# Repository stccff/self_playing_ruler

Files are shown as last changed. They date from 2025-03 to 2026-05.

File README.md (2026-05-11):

# Cyberuler: A Self-Playing Ruler

[English](README.md) | [中文](README_zh.md)


[]()

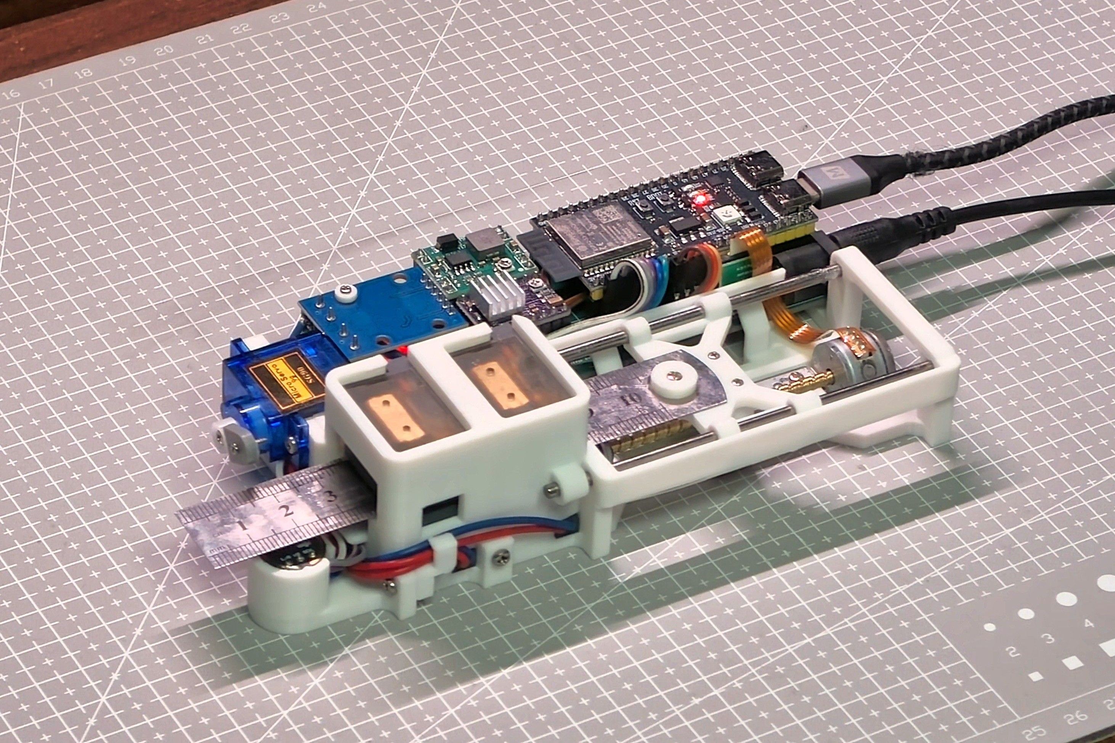
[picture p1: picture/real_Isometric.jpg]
Cyberuler


> An automated musical instrument that turns an ordinary steel ruler into a playable synthesizer — controlled by stepper motors, servos, electromagnets, and MIDI.

## Contents

- ✨ [Features](#features)
- 🎵 [A Note on Timbre](#a-note-on-timbre)
- 📂 [Repository Structure](#repository-structure)
- 🛠️ [Hardware at a Glance](#hardware-at-a-glance)
- ⚙️ [PCB Configuration Options](#pcb-configuration-options)
- 🚀 [Getting Started](#getting-started)
  - [Build Prerequisites](#build-prerequisites)
  - [Serial Terminal Commands](#serial-terminal-commands)
- 🗺️ [Roadmap](#roadmap-the-stationery-band)
- 👤 [Author](#author)
- 📄 [License](#license)

## 🎥 Demo



## ✨ Features

- **Pitch Control:** A stepper motor with a lead screw slides the ruler to change the effective vibrating length, producing different pitches.
- **Plucking Mechanism:** A high-speed servo strums the ruler. Four electromagnets (H-bridge driven, two top and two bottom) clamp and release the ruler for clean note articulation.
- **Acoustic Calibration:** An INMP441 I2S microphone captures the ruler's real acoustic response. Fast Fourier Transform (FFT) analysis builds a frequency-to-position mapping — no manual tuning required.
- **NLS Curve Fitting:** Uses Levenberg-Marquardt nonlinear least squares to fit measured frequency data to a `f = k/(pos + a)² + b` model for accurate pitch interpolation across the full range.
- **USB MIDI Input:** Connects as a USB MIDI device via TinyUSB. Responds to Note On/Off messages with velocity sensitivity — play it live from any MIDI keyboard or DAW.
- **USB Microphone:** The I2S microphone is also exposed as a USB Audio (UAC 2.0) input — the ruler doubles as a USB mic for your computer.
- **Serial Terminal REPL:** Built-in command-line interface with line editing, ANSI arrow-key navigation, and command history. Full control over motors, calibration, and diagnostics.

## 🎵 A Note on Timbre

A vibrating string (guitar, piano) follows the wave equation — its overtones are integer multiples of the fundamental, producing a familiar harmonic sound. A steel ruler, however, is a cantilever beam governed by the Euler-Bernoulli beam equation. Under one-end-fixed, one-end-free boundary conditions, its natural frequencies are:

$$\omega_n = \beta_n^2 \sqrt{\frac{EI}{\rho A L^4}}$$

where $\beta_n$ are roots of $1 + \cos\beta \cosh\beta = 0$. The first overtone is roughly **6.26×** the fundamental, and the second is **17.55×** — neither is an integer multiple.

This means the ruler's overtones are inherently inharmonic. Calibration ensures the fundamental frequency is pitch-accurate, but the overtone structure is a physical given — the instrument will always carry a raw, slightly "imperfect" timbre. That is not a flaw; it is the character of the instrument.

## 📂 Repository Structure

| Directory | Description |
|---|---|
| `v1/code/` | ESP-IDF firmware (C) — motor control, FFT, USB MIDI, REPL terminal |
| `v1/model_A_1.2/` | SolidWorks 3D models + printable STL files |
| `v1/model_legacy/` | Archived older model versions (A_1.0, A_1.1, B) |
| `v1/pcb/` | PCB design files (STEP, Gerber), [OSHWHub project](https://oshwhub.com/stccff/self_play_ruler) |
| `v1/bom_zh.xlsx` | Bill of materials |
| `prototype/` | Early prototype — firmware, Python host scripts, 3D models |
| `tools/` | Auxiliary tools and drivers |
| `picture/` | Project photos, renders, and diagrams |

## 🛠️ Hardware at a Glance

- **MCU:** ESP32-S3 DevKitC
- **PCB:** Custom mainboard (fabricated by JLCPCB) — integrates power, motor drivers, microphone, USB MIDI, and USB Audio. Gerber files in `v1/pcb/`, [OSHWHub project page](https://oshwhub.com/stccff/self_play_ruler)
- **Stepper Driver:** DRV8825 module (A4988 optional)
- **Electromagnet Driver:** L9110S module
- **Voltage Regulator:** MP1845EN module (Mini360 optional)
- **Stepper Motor:** Lead-screw stepper salvaged from a CD-ROM drive
- **Servo:** SG90 (strumming)
- **Electromagnets:** x4 — 2 top, 2 bottom
- **Audio:** INMP441 I2S microphone
- **Power:** 12V DC barrel jack (external power supply required)
- **Chassis:** 3D-printed parts + 150mm steel ruler

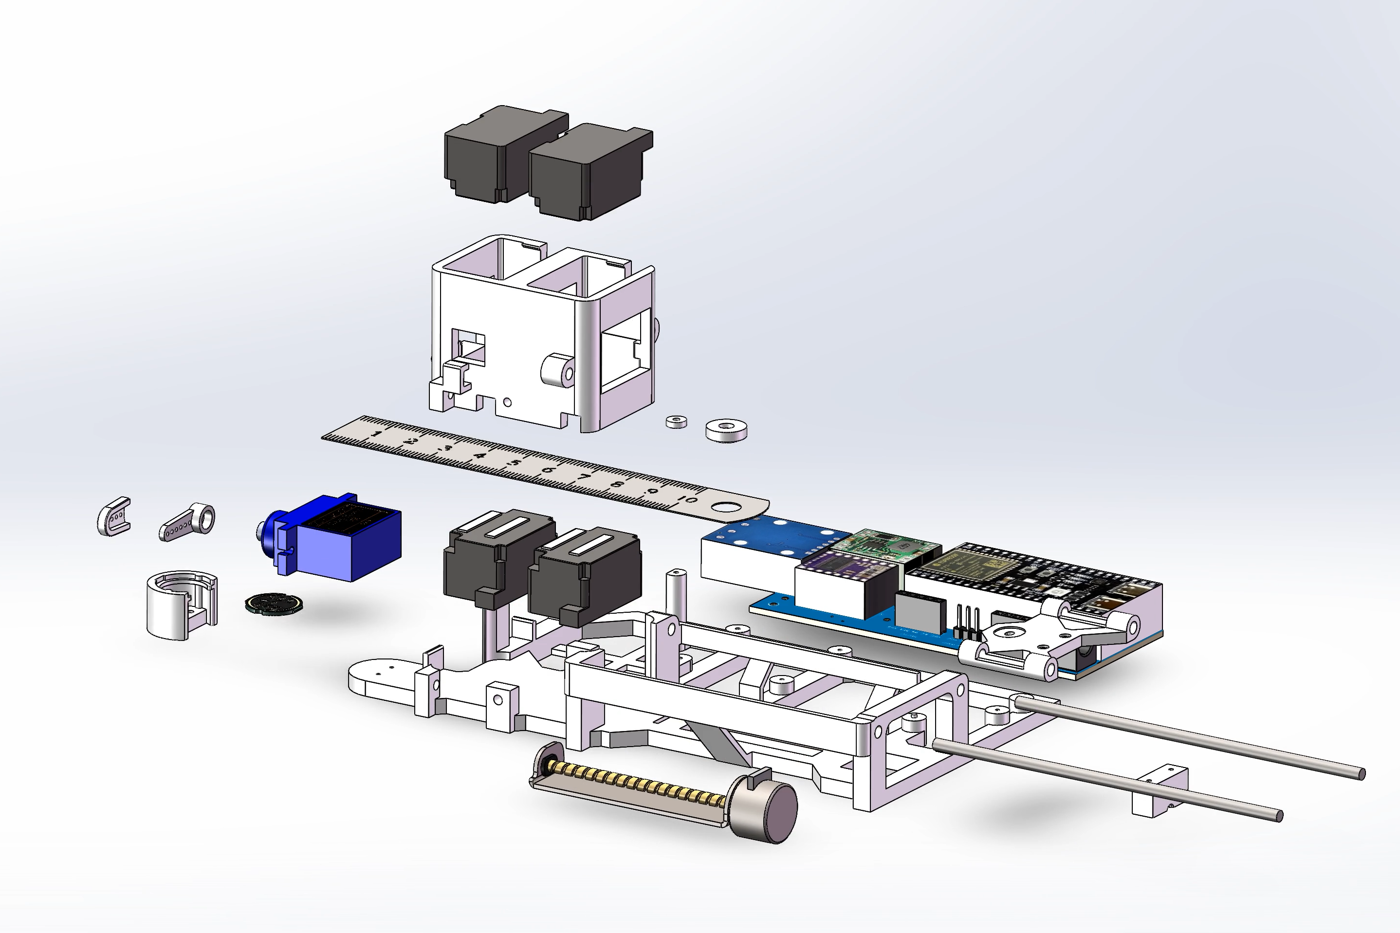
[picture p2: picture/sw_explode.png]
Exploded view


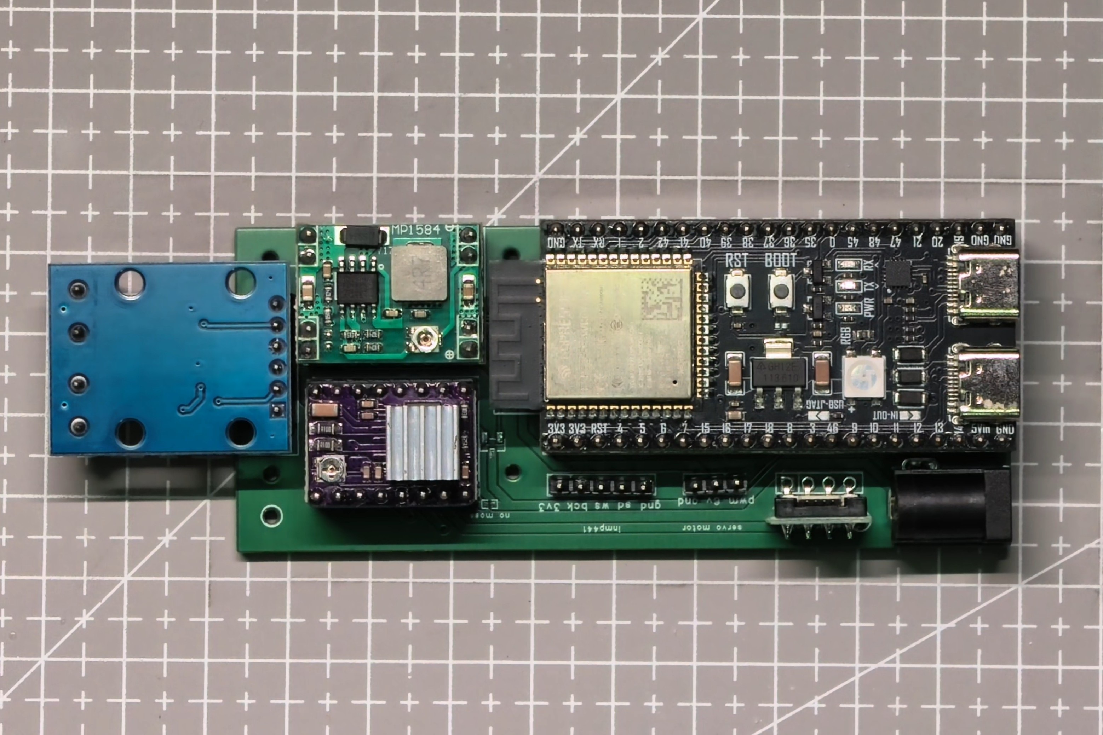
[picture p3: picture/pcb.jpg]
Custom PCB


See `v1/bom_zh.xlsx` for the detailed bill of materials.

> ⚠️ **Important Notes:**
> - The ESP32-S3 DevKitC is powered via USB. The 12V DC input supplies the motors and drivers only — the device will not function without USB connected.
> - If the **SGM2521YS8** power-switch IC is not populated on the PCB, do **not** disconnect USB while 12V power remains connected. Doing so cuts power to the ESP32, leaving the DRV8825 control pins floating and the stepper motor in an abnormal state that causes overheating.
> - Set the **SG90 servo supply voltage to 6V**. The firmware's strum timing was calibrated at 6V; a different voltage will throw off the timing.
> - Set the **DRV8825 current limit** appropriately. Too low and the stepper motor will stall; too high and it will overheat.

## ⚙️ PCB Configuration Options

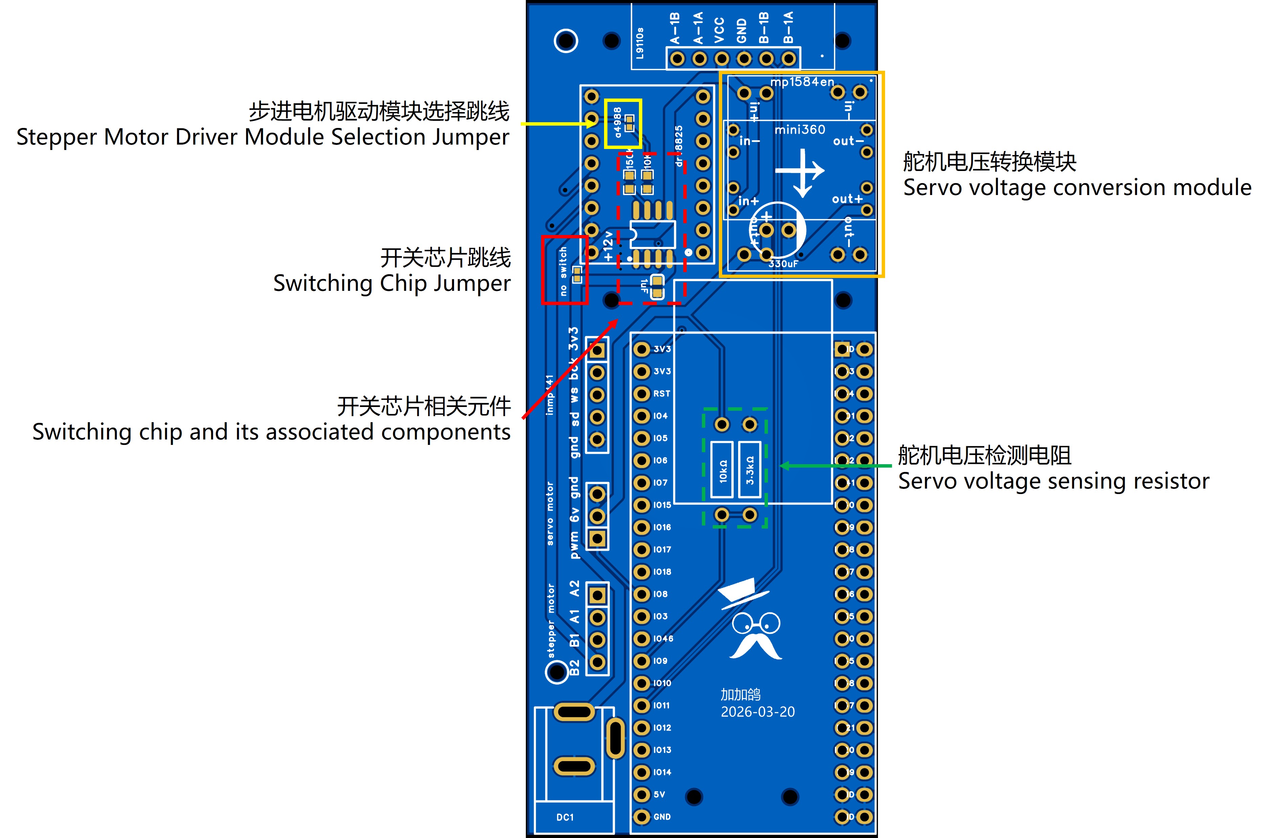
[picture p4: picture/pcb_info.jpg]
PCB jumpers and options


- **Stepper driver:** DRV8825 (default) or A4988 — solder the jumper pads when using A4988.
- **Servo voltage regulator:** MP1845EN (default) or Mini360.
- **Power-switch IC (SGM2521YS8):** Optional — prevents the stepper driver from entering an abnormal state when the MCU loses power (see Important Notes above).
- **Servo voltage sense resistor:** Optional — enables ADC-based voltage monitoring from the dev board, useful for tuning servo voltage without a multimeter.

## 🚀 Getting Started

1. **Print the parts:** STL files are in `v1/model_A_1.2/output/`.
2. **Assemble the hardware:** Mount motors, ruler, electromagnets, and PCB onto the printed chassis.
3. **Flash the firmware:** Build and upload the ESP-IDF project in `v1/code/` to your ESP32-S3.
4. **Calibrate:** Press the BOOT button on the dev board (single-click triggers auto-calibration), or run the `ftinit` command via the serial terminal. The microphone listens as the ruler is plucked across its range to build the pitch map.

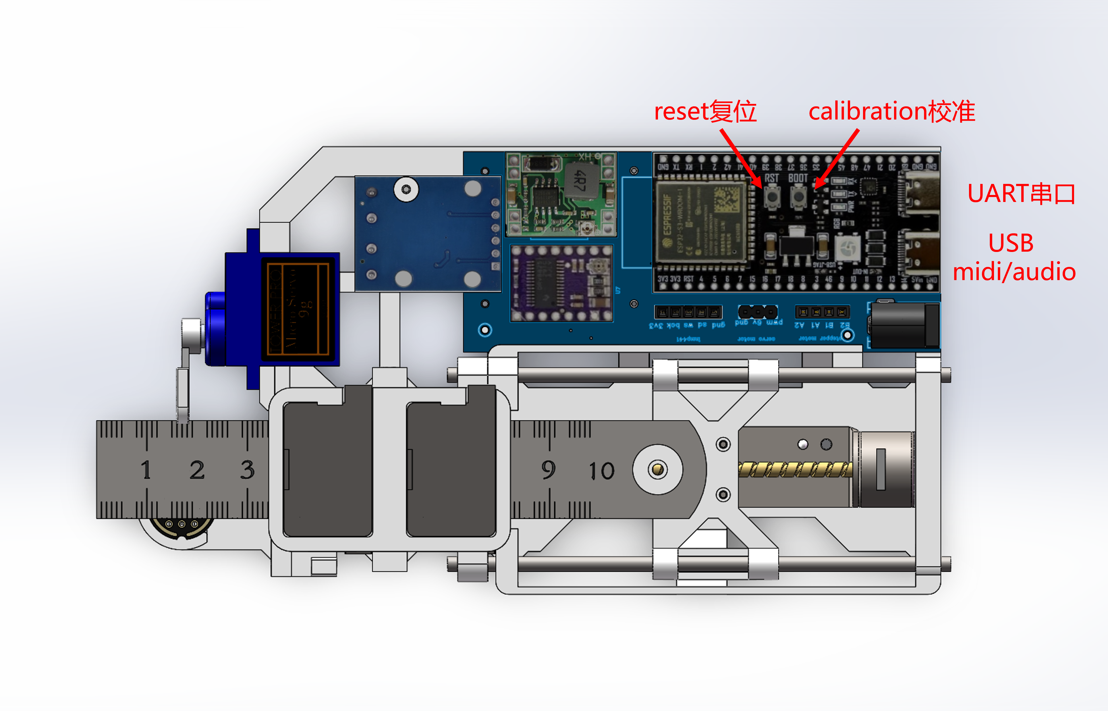
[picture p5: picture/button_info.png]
BOOT button for calibration

5. **Play:** Connect a USB MIDI keyboard, or use the serial terminal (`p` command) to play notes directly.

### Build Prerequisites

- **ESP-IDF** v5.0 or later (target: ESP32-S3)
- Dependencies (auto-resolved by IDF Component Manager):
  - `espressif/esp-dsp` — FFT library
  - `espressif/tinyusb` — USB MIDI device stack
  - `espressif/button` — GPIO button driver
  - `espressif/led_strip` — WS2812 RGB LED driver

```bash
cd v1/code
idf.py set-target esp32s3
idf.py build
idf.py -p <PORT> flash
```

### Serial Terminal Commands

Connect via UART (115200 baud) to access the REPL. Key commands:

| Command | Description |
|---|---|
| `help` | List all available commands |
| `ftinit` | Rebuild frequency calibration table |
| `p <note>` | Play a note by numbered musical notation (e.g. `p 1.`) |
| `midivelocity <0\|1>` | Toggle MIDI velocity sensitivity |
| `compiletime` | Print firmware build timestamp |

## 🗺️ Roadmap: The Stationery Band

The Self-Playing Ruler is the first instrument in a larger vision — a full desk-sized automated orchestra built from everyday stationery.

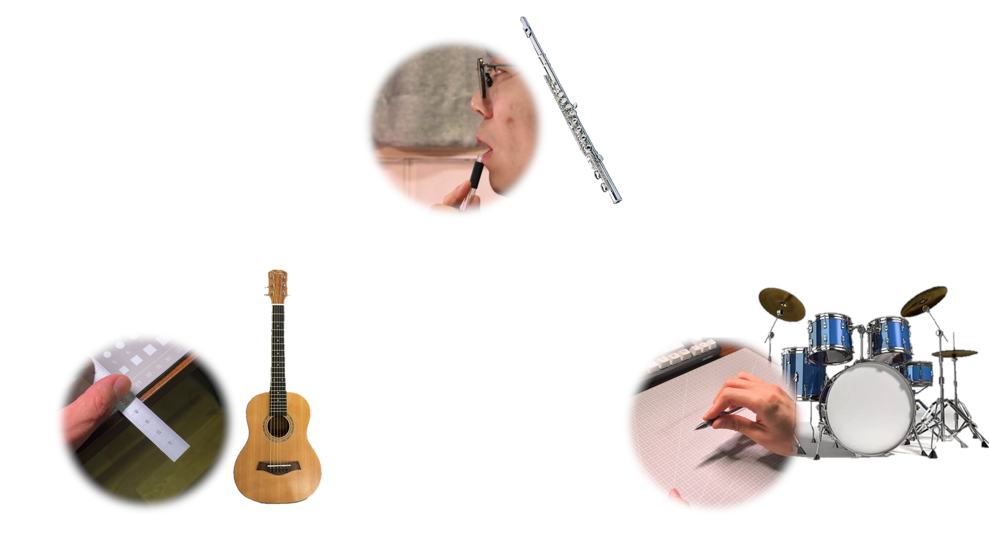
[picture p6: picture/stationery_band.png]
Stationery Band


- [x] **The Guitar/Bass:** Cyberuler (This project)
- [ ] **The Flute:** Automated Wind Pen
- [ ] **The Drums:** Percussive Pen and Desk Tappers
- [ ] **The Conductor:** Central sync hub for all instruments

## 👤 Author

**stccff** — [github.com/stccff](https://github.com/stccff) — [913602792@qq.com](mailto:913602792@qq.com)

Feedback, questions, and build stories are always welcome. If you make your own, I'd love to see it.

## 📄 License

This project is licensed under [CC BY-NC-SA 4.0](https://creativecommons.org/licenses/by-nc-sa/4.0/) — you are free to share and adapt for non-commercial purposes, with attribution and under the same license.

See the [LICENSE](LICENSE) file for details.

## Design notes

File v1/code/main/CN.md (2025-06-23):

# 使用说明

1.傅里叶变换，如果内存不够用，可以使用psram，需要在menuconfig中配置mode(quad/oct)
2.需要配置硬件版本

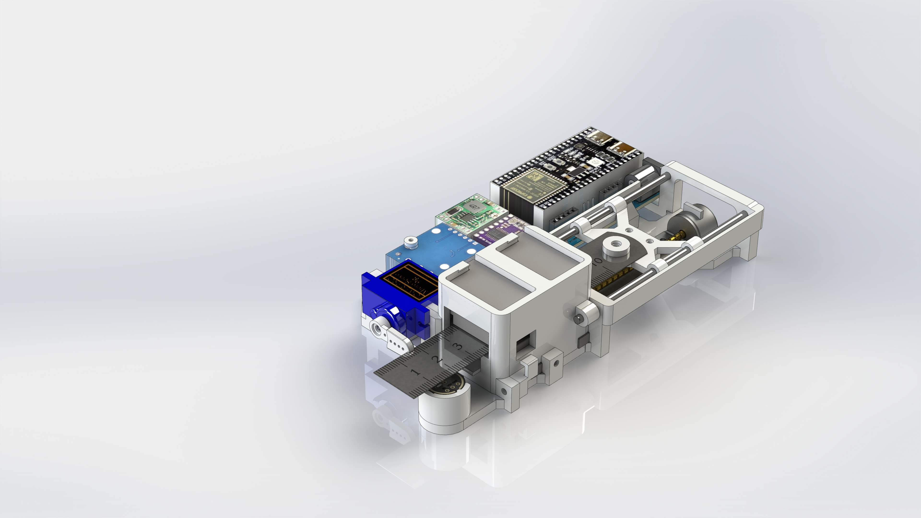
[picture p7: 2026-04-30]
picture/render_photo360.JPG

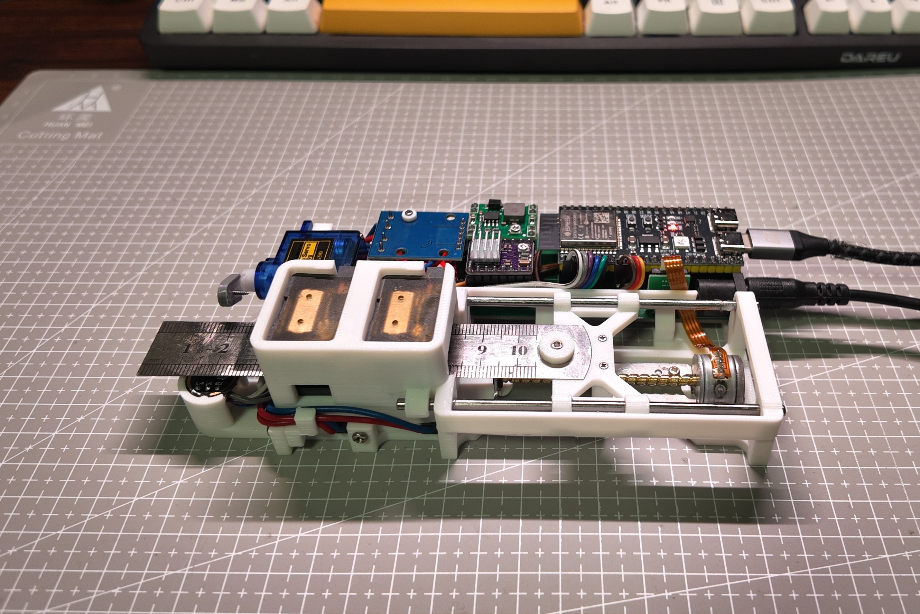
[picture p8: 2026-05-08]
picture/real_front.jpg

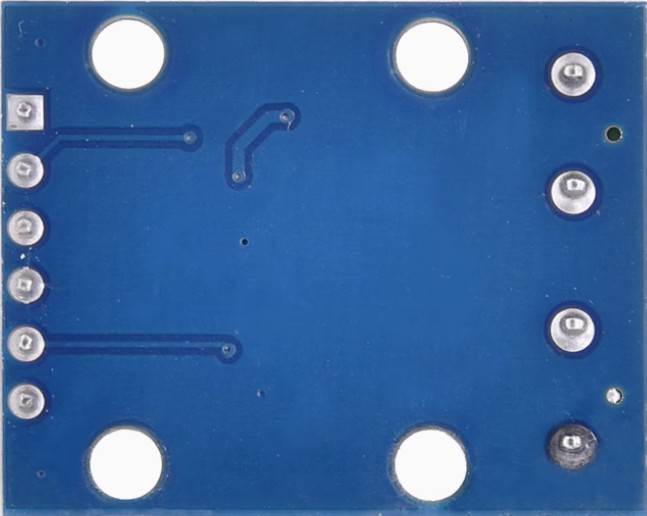
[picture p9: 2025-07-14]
v1/model_A_1.2/texture/l9110s.jpg

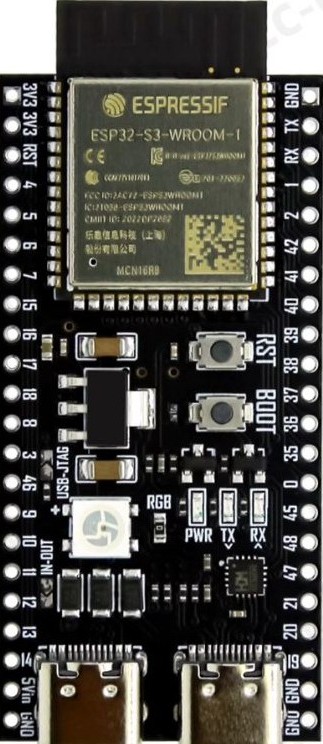
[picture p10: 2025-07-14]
v1/model_A_1.2/texture/esp32s3-devkitc.jpg

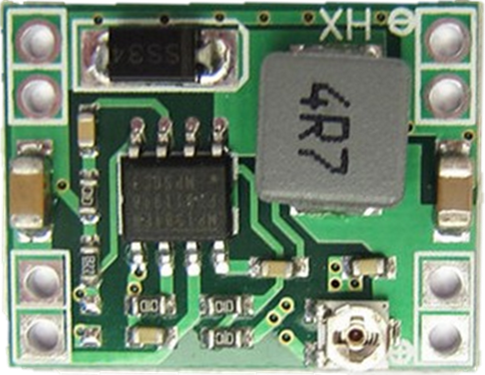
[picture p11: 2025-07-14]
v1/model_A_1.2/texture/mp1584en.png

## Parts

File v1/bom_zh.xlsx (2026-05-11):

是否可选 | 类别 | 名称 | 连接对象 | 数量 | 参考单价 | 共计 | 参考购买链接 | 开源链接
必要 | 器件 | esp32s3-devkitc开发板 |  | 1 | 27.9 | 27.9 | https://item.taobao.com/item.htm?abbucket=20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
必要 | 器件 | drv8825/a4988步进电机驱动模块 |  | 1 | 4.7 | 4.7 | https://detail.tmall.com/item.htm?id=609793364367&skuId=4291793301378
必要 | 器件 | MP1584EN/mini360 可调降压模块 |  | 1 | 1.57 | 1.57 | https://item.taobao.com/item.htm?abbucket=20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
必要 | 器件 | sg90舵机 |  | 1 | 4.2 | 4.2 | https://detail.tmall.com/item.htm?id=678498890304&skuId=5719859296396
必要 | 器件 | Y15-56丝杆步进电机（光驱拆机） |  | 1 | 4.9 | 4.9 | https://item.taobao.com/item.htm?id=642594293054
必要 | 器件 | 双L9110s H桥模块 |  | 1 | 2.3 | 2.3 | https://item.taobao.com/item.htm?id=654074095766&skuId=4712438424221
必要 | 器件 | inmp441数字麦克风模块 |  | 1 | 3.8 | 3.8 | https://item.taobao.com/item.htm?id=608292096518
必要 | 器件 | DC12V-24V电磁铁（拆机） |  | 4 | 1.9 | 7.6 | https://item.taobao.com/item.htm?id=578507772290
必要 | 器件 | DC-12V2A直流电源？？？？ |  | 1 | 16 | 16 | https://item.taobao.com/item.htm?detail_redpacket_pop=true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
必要 | 器件 | usb type-c数据线 |  | 2 | 1.9 | 3.8 | https://item.taobao.com/item.htm?abbucket=20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
必要 | 器件 | 4P FPC 1.0mm -> 2.54转换板 |  | 1 | 1.4 | 1.4 | https://item.taobao.com/item.htm?from=cart&id=552721736398&skuId=4760839875224
必要 | 结构 | 结构模型 |  | 1 | 10 | 10 | 3D打印
必要 | 结构 | 10cm超薄钢尺 |  | 1 | 0.4 | 0.4 | https://item.taobao.com/item.htm?id=592441007488&skuId=4073794208655
必要 | 结构 | 3mm*10cm光轴 |  | 2 | 0.68 | 1.36 | https://detail.tmall.com/item.htm?id=680516964370&skuId=5675436564491
必要 | 结构 | 润滑脂 |  | 1 | 1 | 1
必要 | 结构 | M2*5？圆头螺丝 |  | 3 | 0.05 | 0.15 | https://item.taobao.com/item.htm?id=755201657209&skuId=5379709963747
必要 | 结构 | M2*5螺帽 |  | 3 | 0.05 | 0.15 | https://item.taobao.com/item.htm?id=755201657209&skuId=5379709963747
必要 | 结构 | M2.5*10自攻螺丝 |  | 5 | 0.05 | 0.25 | https://item.taobao.com/item.htm?id=755201657209&skuId=5379709963747
必要 | 结构 | M1.4*7自攻螺丝 |  | 10 | 0.05 | 0.5 | https://detail.tmall.com/item.htm?id=682216315966
必要 | PCB | 主板PCB |  | 1 | 0 | 0 | 嘉立创PCB免费打样
必要 | 元件 | 1x22P排母 | esp32s3 | 2 | 0.22 | 0.44 | https://item.taobao.com/item.htm?id=15813904618
必要 | 元件 | 1x8P排母 | drv8825 | 2 | 0.12 | 0.24 | https://item.taobao.com/item.htm?id=15813904618
必要 | 元件 | 1x2P排母 | MP1584EN | 4 | 0.07 | 0.28 | https://item.taobao.com/item.htm?id=15813904618
必要 | 元件 | 1x6P排母 | L9110s | 1 | 0.1 | 0.1 | https://item.taobao.com/item.htm?id=15813904618
必要 | 元件 | 1x40P排针（掰开使用） | 多个 | 1 | 0.1 | 0.1 | https://item.taobao.com/item.htm?id=14591564405
必要 | 元件 | 杜邦线（约21cm） | mic | 6 | 0.1 | 0.6 | https://detail.tmall.com/item.htm?id=14466195609&skuId=5922240227983
必要 | 元件 | DC电源插座，5.5-2.1mm |  | 1 | 0.06 | 0.06 | https://item.taobao.com/item.htm?id=14986857930
必要 | 元件 | 电解电容330uF |  | 1 | 0.15 | 0.15
可选 | 元件 | 直插电阻10k |  | 1 | 0.02 | 0.02
可选 | 元件 | 直插电阻3.3k |  | 1 | 0.02 | 0.02
可选 | 元件 | 负载开关SGM2521YS8G/TR |  | 1 | 5 | 5
可选 | 元件 | 贴片电容1uF |  | 1 | 0.05 | 0.05
可选 | 元件 | 贴片电阻10K |  | 1 | 0.05 | 0.05
可选 | 元件 | 贴片电阻150K |  | 1 | 0.05 | 0.05
 |  |  |  |  | 总计 | 93.95

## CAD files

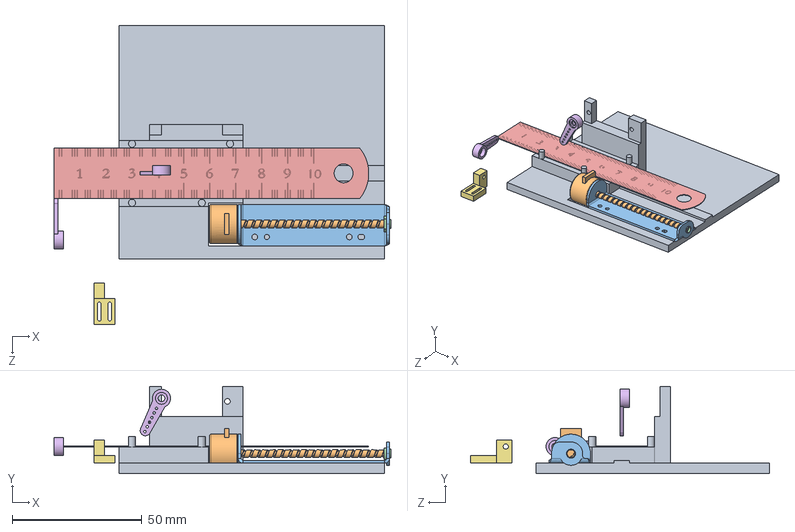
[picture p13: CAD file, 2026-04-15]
prototype/model/尺子演奏器验证机.SLDASM
129.8 x 33.6 x 115.2 mm
步进电机
丝杆底座
丝杆衬套
10cm薄尺
servo_horn(sg90) x 2
底板
舵机固定架L镜向

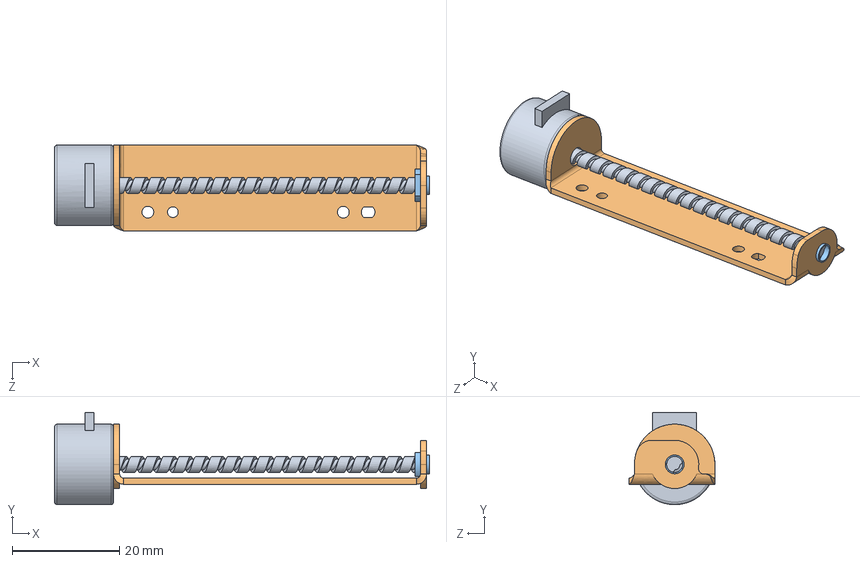
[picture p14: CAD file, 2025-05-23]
prototype/model/光驱丝杆步进电机.SLDASM
69.8 x 17.2 x 16.0 mm
步进电机
丝杆底座
丝杆衬套

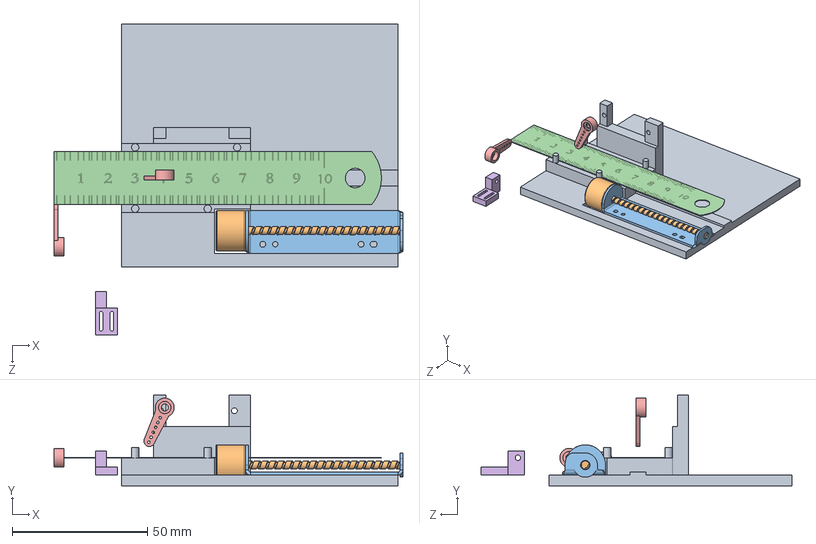
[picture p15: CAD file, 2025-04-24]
prototype/model/动画.SLDASM
129.2 x 33.6 x 115.0 mm
步进电机
丝杆底座
10cm薄尺
servo_horn(sg90) x 2
底板
舵机固定架L镜向

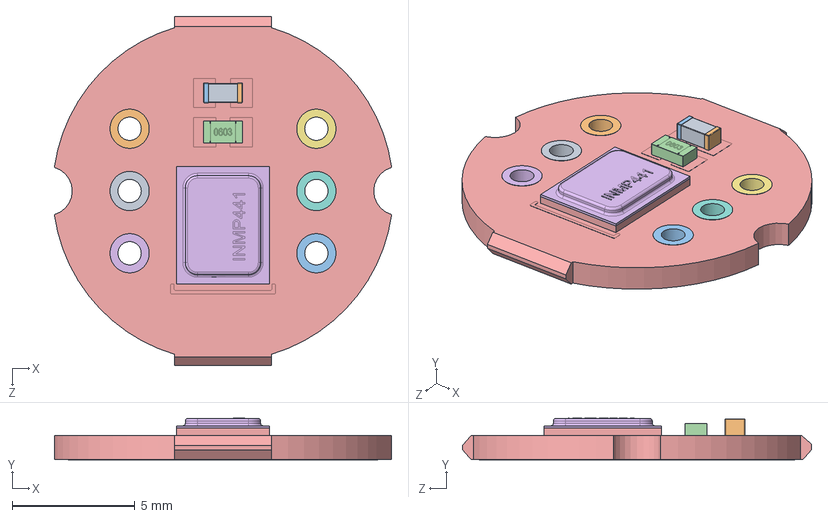
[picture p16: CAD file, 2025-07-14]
v1/model_A_1.2/INMP441.SLDASM
13.8 x 1.70 x 14.2 mm
Part 3.step
Part 2.step
Part 1.step
0603 Resistor.step
INMP441 I2S Microphone Module.step
INMP441 I2S Microphone Module-0.step
INMP441 I2S Microphone Module-1.step
INMP441 I2S Microphone Module-2.step
INMP441 I2S Microphone Module-3.step
INMP441 I2S Microphone Module-4.step
INMP441 I2S Microphone Module-5.step
INMP441 I2S Microphone Module-6.step
INMP441 I2S Microphone Module-7.step
INMP441 I2S Microphone Module-8.step

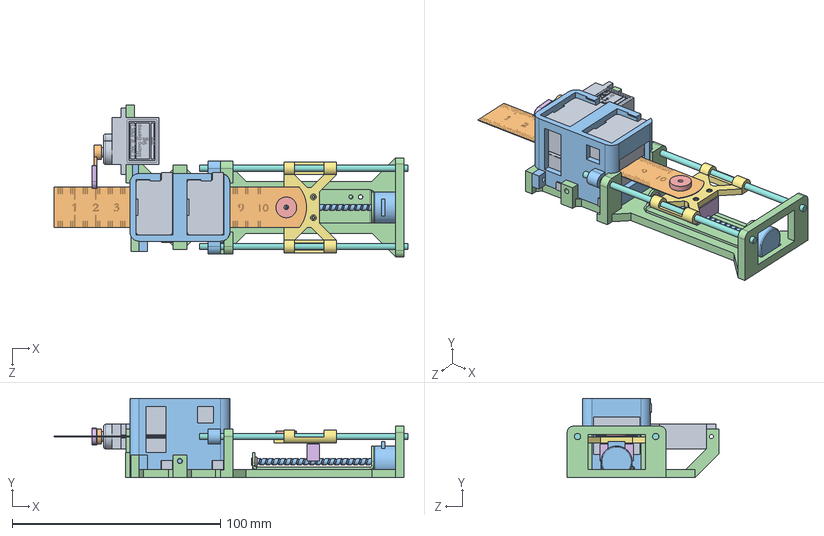
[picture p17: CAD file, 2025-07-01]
v1/model_A_1.2/钢尺琴A_1.2.SLDASM
169.9 x 38.1 x 72.8 mm
电磁铁 x 4
10cm薄尺
步进电机
丝杆底座
丝杆衬套
丝杆连接器
滑块（新）
光轴3x100 x 2
servo_motor(SG90)
servo_horn(sg90)
电磁铁固定座
底座（新）
固定块
拨片

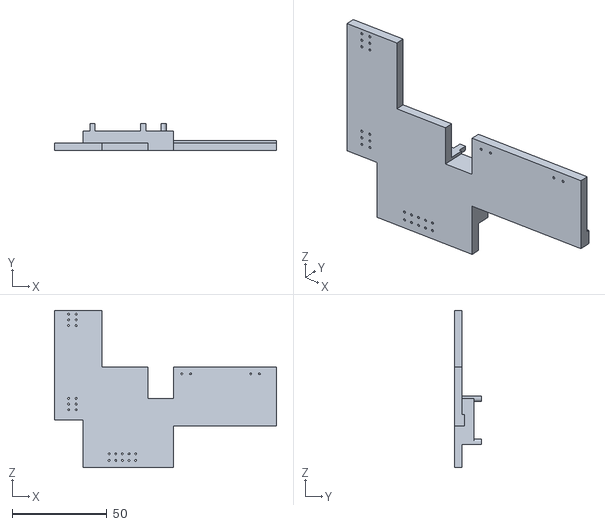
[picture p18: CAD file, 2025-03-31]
prototype/model/stl/尺子演奏器验证机 - 底板-1.STL
117.3 x 14.3 x 83.0

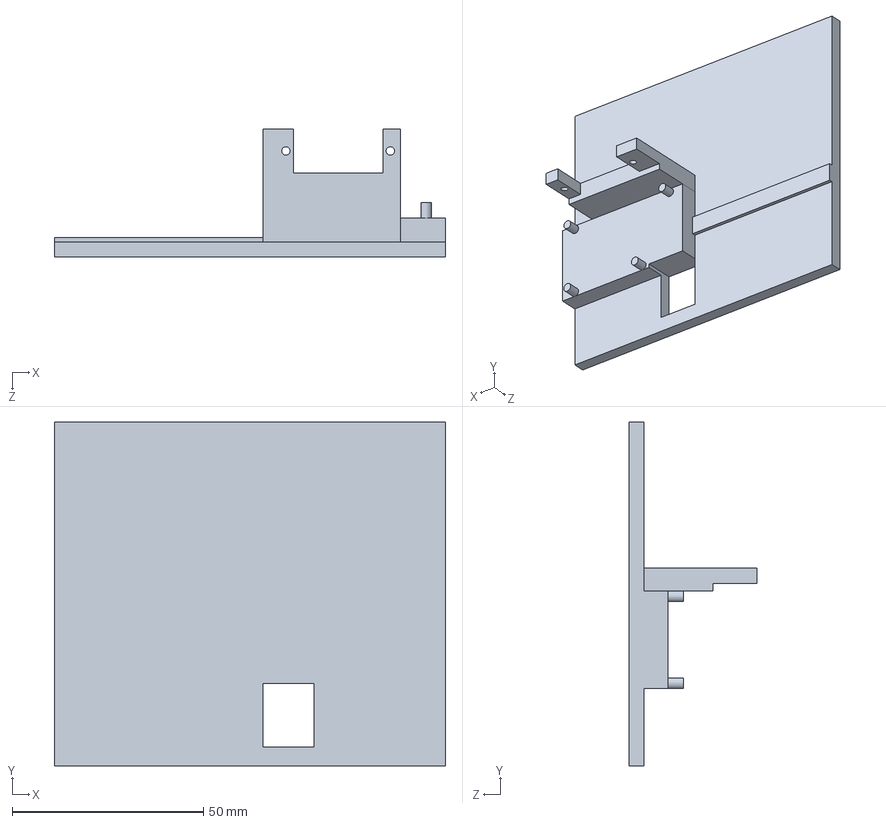
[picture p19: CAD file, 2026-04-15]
prototype/model/底板.SLDPRT
102.3 x 89.9 x 33.6 mm

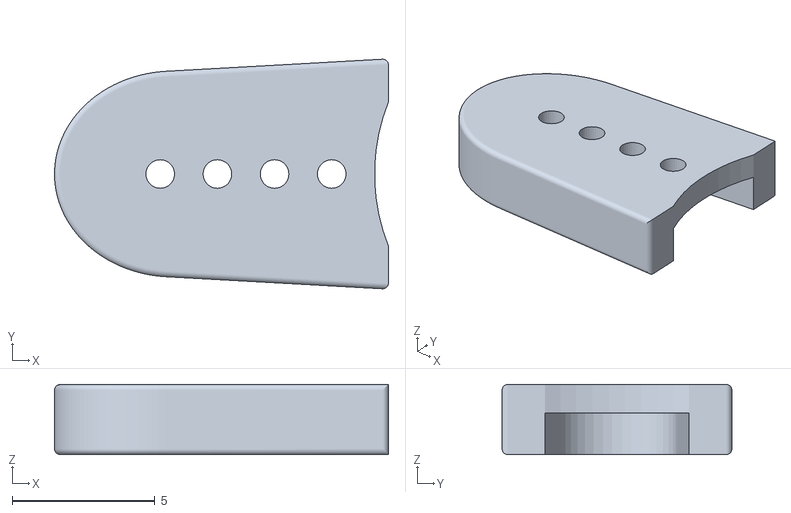
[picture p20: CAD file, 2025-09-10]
v1/model_A_1.2/output/钢尺琴A_1.2 - 拨片+-1.STL
11.7 x 8.03 x 2.45

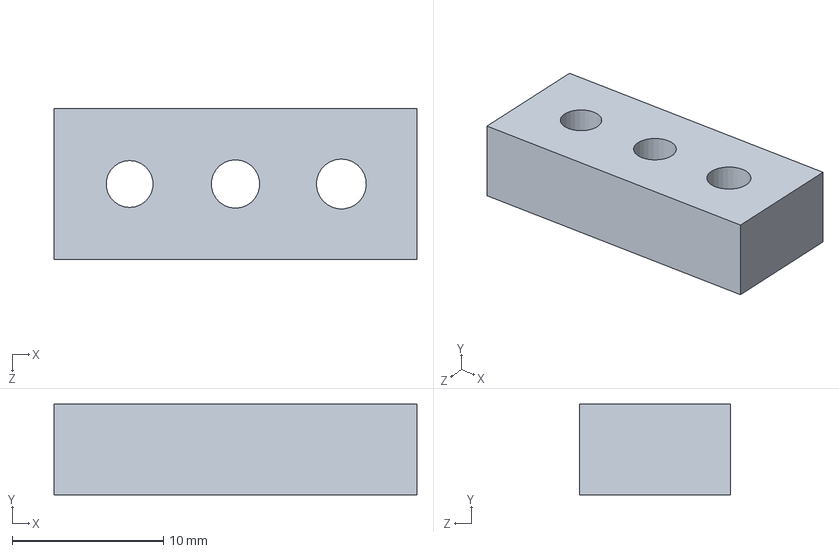
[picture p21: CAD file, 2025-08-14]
v1/model_A_1.2/test/钢轴孔径测试.SLDPRT
24.0 x 6.00 x 10.0 mm

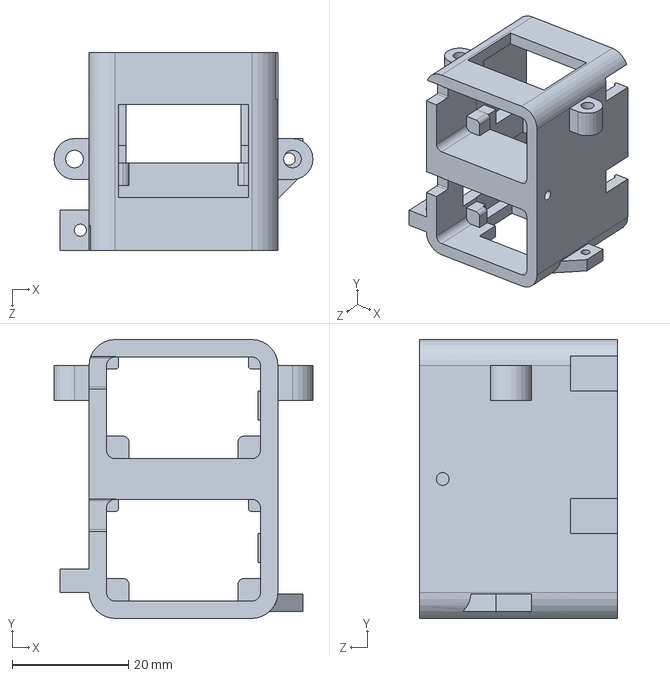
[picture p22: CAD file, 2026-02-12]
v1/model_A_1.2/电磁铁固定座.SLDPRT
44.6 x 48.0 x 34.1 mm

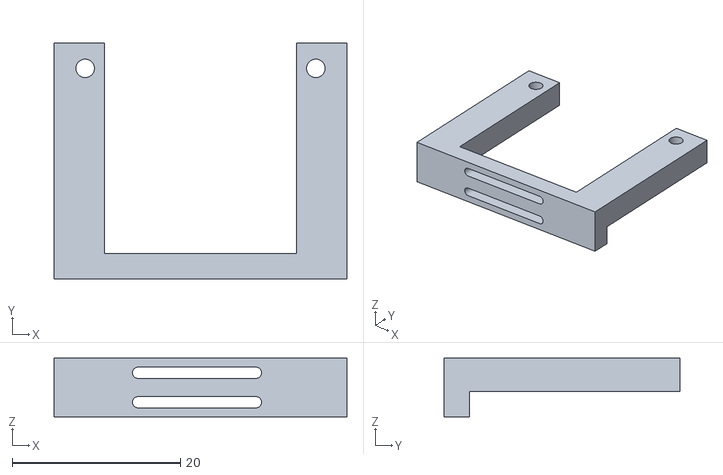
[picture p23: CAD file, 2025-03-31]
prototype/model/stl/尺子演奏器验证机 - 舵机固定器(按压)-1.STL
34.8 x 28.0 x 7.00

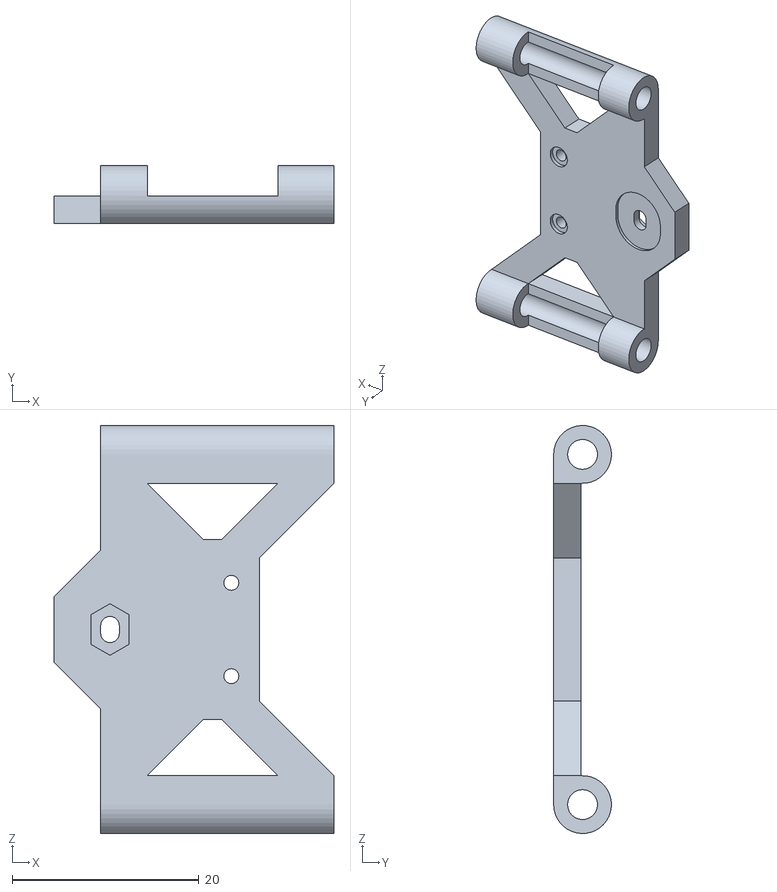
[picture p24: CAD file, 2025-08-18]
v1/model_A_1.2/output/钢尺琴A_1.2 - 滑块（新）-1.STL
30.0 x 6.19 x 43.7

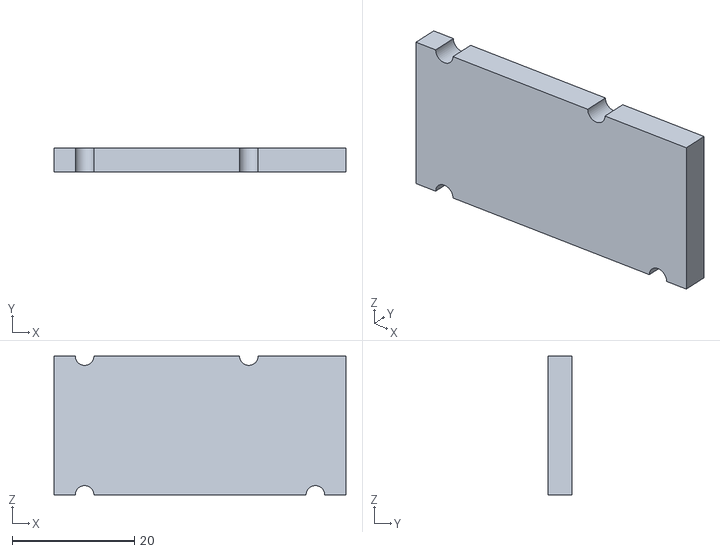
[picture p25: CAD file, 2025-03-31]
prototype/model/stl/尺子演奏器验证机 - 盖板-1.STL
47.7 x 4.00 x 22.7

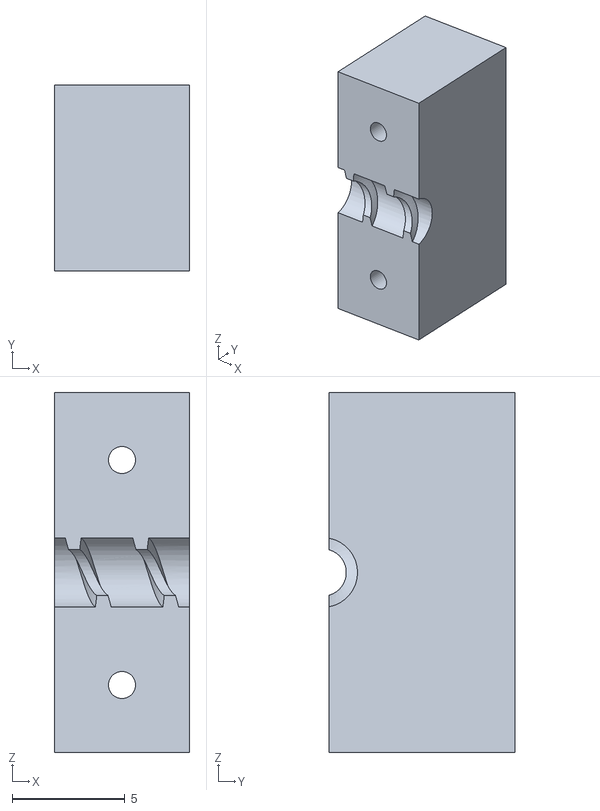
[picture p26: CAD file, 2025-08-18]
v1/model_A_1.2/output/钢尺琴A_1.2 - 丝杆连接器_优化版-1.STL
6.00 x 8.28 x 16.0

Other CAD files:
v1/model_A_1.2/光驱丝杆步进电机.SLDASM
prototype/model/舵机固定架L镜向.SLDPRT
v1/model_A_1.2/mic固定座.SLDPRT
prototype/model/舵机固定架L.SLDPRT
prototype/model/stl/尺子演奏器验证机 - 10cm薄尺-1.STL
prototype/model/stl/尺子演奏器验证机 - servo_horn(sg90)-1.STL
prototype/model/stl/尺子演奏器验证机 - servo_horn(sg90)-2.STL
prototype/model/stl/尺子演奏器验证机 - servo_motor(SG90)-1.STL
prototype/model/stl/尺子演奏器验证机 - servo_motor(SG90)-2.STL
prototype/model/stl/尺子演奏器验证机 - 光驱丝杆步进电机-1 丝杆底座-1.STL
prototype/model/stl/尺子演奏器验证机 - 光驱丝杆步进电机-1 步进电机-2.STL
prototype/model/stl/尺子演奏器验证机 - 固定帽-1.STL
prototype/model/stl/尺子演奏器验证机 - 滑块-1.STL
prototype/model/stl/尺子演奏器验证机 - 舵机固定架L-1.STL
prototype/model/stl/尺子演奏器验证机 - 舵机固定架L镜向-3.STL
prototype/model/丝杆衬套.SLDPRT
prototype/model/固定帽.SLDPRT
prototype/model/滑块.SLDPRT
prototype/model/盖板.SLDPRT
prototype/model/舵机固定器(按压).SLDPRT
v1/model_A_1.2/10cm薄尺.SLDPRT
v1/model_A_1.2/output/钢尺琴A_1.2 - mic固定座-1.STL
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

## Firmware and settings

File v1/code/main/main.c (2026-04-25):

#include <stdio.h>
#include <stdlib.h>
#include <string.h>
#include "freertos/FreeRTOS.h"
#include "freertos/task.h"
#include "freertos/event_groups.h"
#include "esp_system.h"
#include "esp_log.h"
#include "servo_motor.h"
#include "step_motor.h"
#include "ruler.h"
#include "uart_ctrl.h"
#include "terminal.h"
#include "digital_mic.h"
#include "h_bridge.h"
#include "tinyusb_device.h"
#include "play.h"
#include "nvs_flash.h"
#include "key.h"
#include "rgb_led.h"

#define TAG "MAIN"

/*
 vTaskGetRunTimeStats() 使用
 注意:
 使用 vTaskGetRunTimeStats() 前需使能:
 make menuconfig -> Component config -> FreeRTOS -> configUSE_TRACE_FACILITY
 make menuconfig -> Component config -> FreeRTOS -> Enable FreeRTOS trace facility -> configUSE_STATS_FORMATTING_FUNCTIONS
 make menuconfig -> Component config -> FreeRTOS -> Enable display of xCorelD in vlaskList
 make menuconfig -> Component config -> FreeRTOS -> configGENERATE_RUN_TIME_STATS
 通过上面配置，等同于使能 FreeRTOSConfig.h 中如下三个宏:
 configGENERATE_RUN_TIME_STATS，configUSE_STATS_FORMATTING_FUNCTIONS 和 configSUPPORT_DYNAMIC_ALLOCATION
 */
void print_task_info(char *buff)
{
    /* 打印当前任务列表 */
    vTaskList(buff);
    printf("task\t\tstate\tprio\tstack\ttid\tcore\n");
    printf("%s\n", buff);
    /* 打印任务运行信息 */
    vTaskGetRunTimeStats(buff);
    printf("task_name\trun_cnt\t\tusage\n");
    printf("%s\n", buff);
}

void init_nvs(void)
{
    esp_err_t err = nvs_flash_init();
    if (err == ESP_ERR_NVS_NO_FREE_PAGES || err == ESP_ERR_NVS_NEW_VERSION_FOUND) {
        // NVS partition was truncated and needs to be erased
        // Retry nvs_flash_init
        ESP_ERROR_CHECK(nvs_flash_erase());
        err = nvs_flash_init();
    }
    ESP_ERROR_CHECK(err);
}

void app_main(void)
{
    h_bridge_init();
    init_nvs();
    servo_motor_init();
    stepper_motor_init();
    ruler_init();
    i2s_driver_init();
    play_init();
    terminal_init(8); // terminal setup — must be before uart_init()
    uart_init();
    button_init();
    tinyusb_device_init();
    rgb_led_init();

    vTaskDelay(pdMS_TO_TICKS(1000));

    char *buff = (char *)malloc(2048);
    print_task_info(buff);
    free(buff);

    // while (1) {
    //     vTaskDelay(pdMS_TO_TICKS(1000));
    // }

    return;
}

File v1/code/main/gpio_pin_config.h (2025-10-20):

#ifndef __GPIO_PIN_CONFIG_H__
#define __GPIO_PIN_CONFIG_H__

#include <stdint.h>

/* GPIO 19 20 reserved for usb D+ D- */
/* GPIO 48 reserved for RGB led */

/* I2S port and GPIOs */
#define I2S_BCK_IO      (GPIO_NUM_15)
#define I2S_WS_IO       (GPIO_NUM_16)
#define I2S_DI_IO       (GPIO_NUM_17)

/* H bridge GPIOs */
#ifdef HW_V1_2_TEMP
#define MOTOR_B_1A_IO 10
#define MOTOR_B_1B_IO 11
#define MOTOR_A_1A_IO 12
#define MOTOR_A_1B_IO 13
#else
#define MOTOR_B_1B_IO 10
#define MOTOR_B_1A_IO 11
#define MOTOR_A_1B_IO 12
#define MOTOR_A_1A_IO 13
#endif

/* servo motor GPIOs */
#define SERVO_STRUM_GPIO 8 // GPIO number for strum servo
#ifdef CONFIG_HW_PROTOTYPE
#define SERVO_FRET_GPIO -1  // GPIO number for fret servo
#endif // CONFIG_HW_PROTOTYPE
#define SERVO_PWR_ADC 9

/* stepper motor GPIOs */
#ifdef HW_V1_2_TEMP
#define STEP_MOTOR_GPIO_EN 4
#define STEP_MOTOR_GPIO_STEP 6
#define STEP_MOTOR_GPIO_DIR 21
#define STEP_MOTOR_MODE0_PIN 47
#define STEP_MOTOR_MODE1_PIN 48
#define STEP_MOTOR_MODE2_PIN 45
#else
#define STEP_MOTOR_GPIO_EN 39
#define STEP_MOTOR_GPIO_DIR 1
#define STEP_MOTOR_GPIO_STEP 2
#define STEP_MOTOR_MODE0_PIN 40
#define STEP_MOTOR_MODE1_PIN 41
#define STEP_MOTOR_MODE2_PIN 42
#endif

// trigger GPIO for frequency measurement
#define FREQ_TRIGG_IO 0

// RGB LED GPIO
#define LED_STRIP_GPIO_PIN  48



#endif // __GPIO_PIN_CONFIG_H__

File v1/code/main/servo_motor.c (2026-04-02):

#include "freertos/FreeRTOS.h"
#include "freertos/task.h"
#include "esp_log.h"
#include "driver/mcpwm_prelude.h"
#include "servo_motor.h"
#include "gpio_pin_config.h"
#include "nvs_flash.h"
#include <math.h>
#include "play.h"
#include "step_motor.h"
#include "digital_mic.h"

/* ***************************************************************************************************************** */
/*                                               macro define                                                        */
/* ***************************************************************************************************************** */
// Please consult the datasheet of your servo before changing the following parameters
#define SERVO_MIN_PULSEWIDTH_US 500  // Minimum pulse width in microsecond
#define SERVO_MAX_PULSEWIDTH_US 2500 // Maximum pulse width in microsecond
#define SERVO_MIN_DEGREE -90         // Minimum angle
#define SERVO_MAX_DEGREE 90          // Maximum angle

#define SERVO_TIMEBASE_RESOLUTION_HZ 1000000 // 1MHz, 1us per tick
#define SERVO_TIMEBASE_PERIOD 20000          // 20000 ticks, 20ms

// #define SERVO_STRUM_UP_ANGLE 25
// #define SERVO_STRUM_DOWN_ANGLE -30
#define SERVO_STRUM_ANGLE 28

#ifdef CONFIG_HW_PROTOTYPE
#define SERVO_FRET_UP_ANGLE 70
#define SERVO_FRET_DOWN_ANGLE 85
#endif

#define SERVO_SPEED 0.12 // s/60degree

#define SAMPLE_RATE 8000 // Hz
#define MAX_CALIBRATE_TIMES 25
#define ONECE_SAMPLE_TIMES 3
#define CALI_SAMPLE_TIME 300 // ms
#define CALI_SAMPLE_NUM (CALI_SAMPLE_TIME * SAMPLE_RATE / 1000) // TODO: if change, make sure dma buffer is enough
#define I2S_BIT_WIDTH 24 // TODO: do not define again
#define THRESHOLD_DELTA_PERCENTAGE 0.015 // 1.5%

#define STORAGE_NAMESPACE "servo_motor"
/* ***************************************************************************************************************** */
/*                                               struct define                                                       */
/* ***************************************************************************************************************** */
typedef struct {
    struct {
        char *name;
        int output_gpio;
        int polarity;
        float init_angle;
    } const cfg;
    float offset_angle;
    int offset_angle_r;
    mcpwm_cmpr_handle_t pwm_handle;
    int curr_angle;
} servo_t;
/* ***************************************************************************************************************** */
/*                                               global variable                                                     */
/* ***************************************************************************************************************** */
static const char *TAG = "servo_motor";
TaskHandle_t g_servo_task_handle = NULL;

static servo_t g_servo[] = {
    { // strum servo
        .cfg = {
            .name = "strum",
            .output_gpio = SERVO_STRUM_GPIO,
            .polarity = 1,
            .init_angle = SERVO_STRUM_ANGLE,
        },
        .pwm_handle = NULL,
        .offset_angle = 0,
        .offset_angle_r = 0,
        .curr_angle = 0,
    },
#ifdef CONFIG_HW_PROTOTYPE
    { // fret servo
        .cfg = {
            .name = "fret",
            .output_gpio = SERVO_FRET_GPIO,
            .polarity = 1,
            .init_angle = SERVO_FRET_UP_ANGLE,
        },
        .pwm_handle = NULL,
        .offset_angle = 0xfffffffg,
        .offset_angle_r = 0xfffffffg,
        .curr_angle = SERVO_FRET_UP_ANGLE,
    },
#endif
};



static inline uint32_t angle_to_compare(float angle)
{
    return (angle - SERVO_MIN_DEGREE) * (SERVO_MAX_PULSEWIDTH_US - SERVO_MIN_PULSEWIDTH_US) / (SERVO_MAX_DEGREE - SERVO_MIN_DEGREE) + SERVO_MIN_PULSEWIDTH_US;
}

mcpwm_cmpr_handle_t pwm_create(int output_gpio)
{
    ESP_LOGI(TAG, "Create timer and operator");
    mcpwm_timer_handle_t timer = NULL;
    mcpwm_timer_config_t timer_config = {
        .group_id = 0,
        .clk_src = MCPWM_TIMER_CLK_SRC_DEFAULT,
        .resolution_hz = SERVO_TIMEBASE_RESOLUTION_HZ,
        .period_ticks = SERVO_TIMEBASE_PERIOD,
        .count_mode = MCPWM_TIMER_COUNT_MODE_UP,
    };
    ESP_ERROR_CHECK(mcpwm_new_timer(&timer_config, &timer));

    mcpwm_oper_handle_t oper = NULL;
    mcpwm_operator_config_t operator_config = {
        .group_id = 0, // operator must be in the same group to the timer
    };
    ESP_ERROR_CHECK(mcpwm_new_operator(&operator_config, &oper));

    ESP_LOGI(TAG, "Connect timer and operator");
    ESP_ERROR_CHECK(mcpwm_operator_connect_timer(oper, timer));

    ESP_LOGI(TAG, "Create comparator and generator from the operator");
    mcpwm_cmpr_handle_t comparator = NULL;
    mcpwm_comparator_config_t comparator_config = {
        .flags.update_cmp_on_tez = true,
    };
    ESP_ERROR_CHECK(mcpwm_new_comparator(oper, &comparator_config, &comparator));

    mcpwm_gen_handle_t generator = NULL;
    mcpwm_generator_config_t generator_config = {
        .gen_gpio_num = output_gpio,
    };
    ESP_ERROR_CHECK(mcpwm_new_generator(oper, &generator_config, &generator));

    // set the initial compare value, so that the servo will spin to the center position
    ESP_ERROR_CHECK(mcpwm_comparator_set_compare_value(comparator, angle_to_compare(0)));

    ESP_LOGI(TAG, "Set generator action on timer and compare event");
    // go high on counter empty
    ESP_ERROR_CHECK(mcpwm_generator_set_action_on_timer_event(generator,
                                                              MCPWM_GEN_TIMER_EVENT_ACTION(MCPWM_TIMER_DIRECTION_UP, MCPWM_TIMER_EVENT_EMPTY, MCPWM_GEN_ACTION_HIGH)));
    // go low on compare threshold
    ESP_ERROR_CHECK(mcpwm_generator_set_action_on_compare_event(generator,
                                                                MCPWM_GEN_COMPARE_EVENT_ACTION(MCPWM_TIMER_DIRECTION_UP, comparator, MCPWM_GEN_ACTION_LOW)));

    ESP_LOGI(TAG, "Enable and start timer");
    ESP_ERROR_CHECK(mcpwm_timer_enable(timer));
    ESP_ERROR_CHECK(mcpwm_timer_start_stop(timer, MCPWM_TIMER_START_NO_STOP));
    return comparator;
}

/**
 * @brief this is an IRAM function and not a common API, it is only used for strum action callback function,
 *          which has a high requirement for real-time performance.
 *
 */
void IRAM_ATTR servo_strum_iram_without_fpu(void)
{
    /* Strum */
    int angle = 0;
    if (g_servo[0].curr_angle >= 0) {
        angle = -SERVO_STRUM_ANGLE;
    } else {
        angle = SERVO_STRUM_ANGLE;
    }

    int real_angle = angle + g_servo[0].offset_angle_r;
    ESP_ERROR_CHECK(real_angle < SERVO_MIN_DEGREE || real_angle > SERVO_MAX_DEGREE);
    uint32_t cmp_val = (real_angle - SERVO_MIN_DEGREE) * (SERVO_MAX_PULSEWIDTH_US - SERVO_MIN_PULSEWIDTH_US) /
                        (SERVO_MAX_DEGREE - SERVO_MIN_DEGREE) + SERVO_MIN_PULSEWIDTH_US;
    ESP_ERROR_CHECK(mcpwm_comparator_set_compare_value(g_servo[0].pwm_handle, cmp_val));
    g_servo[0].curr_angle = angle;
}
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

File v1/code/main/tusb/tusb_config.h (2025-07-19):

/*
 * The MIT License (MIT)
 *
 * Copyright (c) 2019 Ha Thach (tinyusb.org)
 *
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
 */

#ifndef _TUSB_CONFIG_H_
#define _TUSB_CONFIG_H_

#ifdef __cplusplus
extern "C" {
#endif

// #define CFG_TUD_USB_SOF 1 // 启用 SOF 回调（好像不需要）

/* 编程指南提到的 */
#define CFG_TUSB_RHPORT0_MODE    (OPT_MODE_DEVICE | OPT_MODE_FULL_SPEED)

#ifndef ESP_PLATFORM
#define ESP_PLATFORM
#endif

// #define CFG_TUSB_OS_INC_PATH   freertos/
// #define CFG_TUSB_OS           OPT_OS_FREERTOS
// #define CFG_TUSB_DEBUG         0
// #define CFG_TUD_ENABLED           1
// CFG_TUSB_MEM_SECTION
// CFG_TUSB_MEM_ALIGN
// CFG_TUD_ENDPOINT0_SIZE


//--------------------------------------------------------------------+
// Board Specific Configuration
//--------------------------------------------------------------------+
// RHPort number used for device can be defined by board.mk, default to port 0
#ifndef BOARD_TUD_RHPORT
#define BOARD_TUD_RHPORT      0
#endif

// RHPort max operational speed can defined by board.mk
#ifndef BOARD_TUD_MAX_SPEED
#define BOARD_TUD_MAX_SPEED   OPT_MODE_DEFAULT_SPEED
#endif

//--------------------------------------------------------------------
// COMMON CONFIGURATION
//--------------------------------------------------------------------

// defined by compiler flags for flexibility
#ifndef CFG_TUSB_MCU
#error CFG_TUSB_MCU must be defined
#endif

// This examples use FreeRTOS
#ifndef CFG_TUSB_OS
#define CFG_TUSB_OS           OPT_OS_FREERTOS
#endif

// Espressif IDF requires "freertos/" prefix in include path
// #if TUSB_MCU_VENDOR_ESPRESSIF
#define CFG_TUSB_OS_INC_PATH  freertos/
// #endif

#ifndef CFG_TUSB_DEBUG
#define CFG_TUSB_DEBUG            1
#endif

// Enable Device stack
#define CFG_TUD_ENABLED           1

// Default is max speed that hardware controller could support with on-chip PHY
#define CFG_TUD_MAX_SPEED         BOARD_TUD_MAX_SPEED

/* USB DMA on some MCUs can only access a specific SRAM region with restriction on alignment.
 * Tinyusb use follows macros to declare transferring memory so that they can be put
 * into those specific section.
 * e.g
 * - CFG_TUSB_MEM SECTION : __attribute__ (( section(".usb_ram") ))
 * - CFG_TUSB_MEM_ALIGN   : __attribute__ ((aligned(4)))
 */
#ifndef CFG_TUSB_MEM_SECTION
#define CFG_TUSB_MEM_SECTION
#endif

#ifndef CFG_TUSB_MEM_ALIGN
#define CFG_TUSB_MEM_ALIGN        __attribute__ ((aligned(4)))
#endif

//--------------------------------------------------------------------
// DEVICE CONFIGURATION
//--------------------------------------------------------------------

#ifndef CFG_TUD_ENDPOINT0_SIZE
#define CFG_TUD_ENDPOINT0_SIZE    64
#endif

//------------- CLASS -------------//
#define CFG_TUD_AUDIO             1
#define CFG_TUD_CDC               0
#define CFG_TUD_MSC               0
#define CFG_TUD_HID               0
#define CFG_TUD_MIDI              1
#define CFG_TUD_VENDOR            0

//--------------------------------------------------------------------
// MIDI DRIVER CONFIGURATION
//--------------------------------------------------------------------
// MIDI FIFO size of TX and RX
#define CFG_TUD_MIDI_RX_BUFSIZE   (TUD_OPT_HIGH_SPEED ? 512 : 64)
#define CFG_TUD_MIDI_TX_BUFSIZE   (TUD_OPT_HIGH_SPEED ? 512 : 64)


//--------------------------------------------------------------------
// AUDIO CLASS DRIVER CONFIGURATION
//--------------------------------------------------------------------

// Have a look into audio_device.h for all configurations
#define CFG_TUD_AUDIO_FUNC_1_SAMPLE_RATE              48000

#define CFG_TUD_AUDIO_FUNC_1_DESC_LEN                 TUD_AUDIO_MIC_ONE_CH_DESC_LEN

#define CFG_TUD_AUDIO_FUNC_1_N_AS_INT                 1
#define CFG_TUD_AUDIO_FUNC_1_CTRL_BUF_SZ              64

#define CFG_TUD_AUDIO_ENABLE_EP_IN                    1
#define CFG_TUD_AUDIO_FUNC_1_N_BYTES_PER_SAMPLE_TX    3         // This value is not required by the driver, it parses this information from the descriptor once the alternate interface is set by the host - we use it for the setup
#define CFG_TUD_AUDIO_FUNC_1_N_CHANNELS_TX            1         // This value is not required by the driver, it parses this information from the descriptor once the alternate interface is set by the host - we use it for the setup
#define CFG_TUD_AUDIO_EP_SZ_IN                        TUD_AUDIO_EP_SIZE(CFG_TUD_AUDIO_FUNC_1_SAMPLE_RATE, CFG_TUD_AUDIO_FUNC_1_N_BYTES_PER_SAMPLE_TX, CFG_TUD_AUDIO_FUNC_1_N_CHANNELS_TX)

#define CFG_TUD_AUDIO_ENABLE_ENCODING                 0
#define CFG_TUD_AUDIO_EP_IN_FLOW_CONTROL              1

#if CFG_TUD_AUDIO_ENABLE_ENCODING

#define CFG_TUD_AUDIO_FUNC_1_EP_IN_SZ_MAX             CFG_TUD_AUDIO_EP_SZ_IN
#define CFG_TUD_AUDIO_FUNC_1_EP_IN_SW_BUF_SZ          CFG_TUD_AUDIO_EP_SZ_IN
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

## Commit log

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2025-03-23 1.Add step motor test program 2.Add the SolidWorks model of the prototype 3.Add the program for the prototype
    [10cm薄尺.SLDPRT, servo_horn(sg90).SLDPRT, servo_motor(SG90).SLDPRT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]
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2025-03-30 1.Combine servo and stepper motor control into the same task to ensure accurate timing and improve playing speed. 2.Optimized the servo control logic to avoid blocking the stepper motor.
    [main.c, servo_motor.c, step_motor.c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]
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2025-03-31 Optimize the solidworks model of ruler cover board
    [固定帽.SLDPRT, 尺子演奏器验证机 - 10cm薄尺-1.STL, 尺子演奏器验证机 - servo_horn(sg90)-1.STL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]
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2025-03-31 Fix the wrong notes in the music score.
    [serial_send.py]
2025-04-24 The model file has been updated to make the prototype look better.
    [10cm薄尺.SLDPRT, servo_horn(sg90).SLDPRT, 丝杆底座.SLDPRT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]
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2025-05-20 v1 model developing 2
    [丝杆连接器-小.SLDPRT, 丝杆连接器.SLDPRT, 夹板底座.SLDPRT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]
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2025-05-22 sg90 fix
    [servo_horn(sg90).SLDPRT, servo_motor(SG90).SLDPRT, 光驱丝杆步进电机.SLDASM]
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2025-05-30 v1 model: modify screw connector
    [丝杆连接器.SLDPRT, 固定块.SLDPRT, 演奏器v1.0_A - 丝杆连接器-2.STL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]
2025-06-03 v1 model: Update the plectrum holder bottom part
    [servo_horn_2(sg90).SLDPRT, 夹板底座.SLDPRT, 夹板底座.STL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]
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2025-06-03 v1 model: model 1.1 developing
    [方案测试.SLDASM, 电磁铁.SLDPRT, 电磁铁固定座.SLDPRT]
2025-06-07 v1 code: fix the stepper motor timing sequence error
    [play.c, test.py, uart_ctrl.c]
2025-06-08 add v1 model 1.1 version
    [10cm薄尺.SLDPRT, Guitar Pick 0.7mm.SLDPRT, famale.SLDPRT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]
2025-06-09 v1 model: merge to last commit
    [钢尺琴A_1.1 - 10cm薄尺-1.STL, 钢尺琴A_1.1 - Guitar Pick 0.7mm-1.STL, 钢尺琴A_1.1 - 光轴3x100-1.STL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]
2025-06-10 v1 model: bug fix
    [丝杆连接器.SLDPRT, 底座（新）.SLDPRT, 滑块（新）.SLDPRT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]
2025-06-10 v1 model: The smooth shaft is fixed on the same component to avoid errors caused by assembly accuracy.
    [丝杆连接器.SLDPRT, 固定块.SLDPRT, 夹板底座.SLDPRT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]
2025-06-11 v1 model: fix some model bug
    [丝杆连接器.SLDPRT, 固定块.SLDPRT, 钢尺琴A_1.1 - 丝杆连接器-1.STL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]
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2025-06-12 v1 model: modify the tight interval size to 0
    [底座（新）.SLDPRT, 电磁铁固定座.SLDPRT, 钢尺琴A_1.1.SLDASM]
2025-06-12 v1 model: add model type B, in developing
    [10cm薄尺.SLDPRT, Guitar Pick 0.7mm.SLDPRT, servo_horn(sg90).SLDPRT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]
2025-06-15 v1 model: add model type B
    [M3螺母.SLDPRT, 丝杆电机.SLDPRT, 丝杆连接器.SLDPRT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]
2025-06-16 v1 model: optimize type B
    [Guitar Pick 0.7mm.SLDPRT, 丝杆连接器.SLDPRT, 压板.SLDPRT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]
2025-06-16 v1 model: fix v1.1 external reference bug
    [丝杆连接器.SLDPRT, 光驱丝杆步进电机.SLDASM, 夹板底座.SLDPRT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]
2025-06-16 v1 model: add type A v1.1.1 model
    [10cm薄尺.SLDPRT, Guitar Pick 0.7mm.SLDPRT, servo_horn(sg90).SLDPRT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]
2025-06-17 v1 model: rename model folder
    [10cm薄尺.SLDPRT, Guitar Pick 0.7mm.SLDPRT, INMP441 I2S Microphone Module v15.step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]
2025-06-17 v1 model: reinforce the e-magnet fixing base
    [丝杆连接器.SLDPRT, 固定块.SLDPRT, 底座（新）.SLDPRT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]
2025-06-17 v1 model: update v1.1.1 stl file
    [电磁铁固定座.STL, 钢尺琴A_1.1.1 - 丝杆连接器-1.STL, 钢尺琴A_1.1.1 - 固定块-1.STL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]
2025-06-17 v1 code: 1.use LOGD to print debug info 2.bug fix
    [h_bridge.c, play.c, uart_ctrl.c]
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2025-06-18 v1 model: do some optimization for v1.1.1
    [丝杆连接器.SLDPRT, 底座（新）.SLDPRT, 滑块（新）.SLDPRT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]
2025-06-18 v1 model: remove redundant parts
    [Guitar Pick 0.7mm.SLDPRT, 夹板上盖.SLDPRT, 夹板底座.SLDPRT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]
2025-06-20 v1 code: 1.Fix legacy note decode bugs. 2.Add electromagnet automatic power off 3.Some refactors
    [main.c, play.c, step_motor.c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]
2025-06-20 v1 model:Modify the reserved clearance of the screw connector to 0.6mm
    [丝杆连接器.SLDPRT, 钢尺琴A_1.1.1 - 丝杆连接器-1.STL, 钢尺琴A_1.1.1.SLDASM]
2025-06-20 v1 model: modify the width of the limiting groove of the ruler
    [底座（新）.SLDPRT, 电磁铁固定座.SLDPRT, 钢尺琴A_1.1.1 - 底座（新）-1.STL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]
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2025-06-28 v1: add bom list
    [bom_cn.xlsx]
2025-07-01 v1 model: rename v1.0 folder
    [Guitar Pick 0.7mm.SLDPRT, INMP441 I2S Microphone Module v15.step, INMP441.SLDASM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]
2025-07-01 v1 model: add model v1.2, inhirented from v1.1.1
    [10cm薄尺.SLDPRT, servo_horn(sg90).SLDPRT, servo_motor(SG90).SLDPRT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]
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2025-07-02 v1 model: model v1.2 in developing
    [INMP441.SLDASM, mic固定座.SLDPRT, 丝杆连接器.SLDPRT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]
2025-07-03 v1 model: v1.2 first version
    [mic固定座.SLDPRT, 丝杆连接器.SLDPRT, 底座（新）.SLDPRT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]
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2025-07-14 v1 model: 1.update pcb0705 and modify model 2.add texture for some electronic submodel
    [INMP441.SLDASM, mic固定座.SLDPRT, 底座（新）.SLDPRT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]
2025-07-15 v1 model:mod interval size between magnet and it's supports form 0.1mm to 0.15mm
    [mic固定座.SLDPRT, 底座（新）.SLDPRT, 电磁铁固定座.SLDPRT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]
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2025-07-24 v1 model: 1.update the foundations to accommodate the wires 2.optimaze the screw rod connector
    [H桥固定塞.SLDPRT, mic固定座.SLDPRT, 丝杆连接器_优化版.SLDPRT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]
2025-07-25 v1 model: update screw rod connector
    [丝杆连接器_优化版.SLDPRT, 丝杆连接器_优化版.STL]
2025-07-25 v1 code: update H bridge model holder
    [H桥固定塞.SLDPRT, mic固定座.SLDPRT, 丝杆连接器_优化版.SLDPRT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]
2025-07-25 v1 model: add wooden shell, but not used
    [mic固定座.SLDPRT, 底座（新）.SLDPRT, 木盒.SLDPRT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]
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2025-07-26 v1 model: update H bridge holder and wire baffle
    [H桥固定塞.SLDPRT, mic固定座.SLDPRT, 垫片.SLDPRT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]
2025-07-30 v1: add the screenplay for final vedio
    [剧本.xlsx]
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2025-08-01 v1 model: some update
    [mic固定座.SLDPRT, 底座（新）.SLDPRT, 木盒.SLDPRT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]
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2025-08-08 v1: modify the screenplay
    [剧本.xlsx]
2025-08-11 v1: Modify the screenplay.The basic process has been written and needs to be improved
    [剧本.xlsx]
2025-08-13 v1 model: Modified the cable management bracket
    [mic固定座.SLDPRT, 底座（新）.SLDPRT]
2025-08-13 v1: update the screenplay
    [剧本.xlsx]
2025-08-14 v1 model: 1. Update the cable management bracket for stepper motor FPCB 2. add test models
    [mic固定座.SLDPRT, 底座（新）.SLDPRT, 钢尺琴A_1.2 - H桥固定塞-1.STL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]
2025-08-15 v1 model: Add handguard and do some optimaize
    [mic固定座.SLDPRT, 固定块.SLDPRT, 底座（新）.SLDPRT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]
2025-08-15 v1: Modify screenplay and rename the excel file
    [screenplay.xlsx, 剧本.xlsx]
2025-08-18 v1 code: Do not strum when removing backlash
    [ruler.c]
2025-08-18 v1 model: do some optimize, such as the mic fixator, the e-magnet fixator and so on
    [mic固定座.SLDPRT, 丝杆连接器_优化版.SLDPRT, 固定块.SLDPRT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]
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2025-09-04 v1: Modify and rename both the screenplay and the BOM.
    [bom_cn.xlsx, bom_zh.xlsx, screenplay.xlsx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]
2025-09-10 v1 model: add the larger lever(add 0.5mm)
    [拨片+.SLDPRT, 钢尺琴A_1.2 - 拨片+-1.STL]
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2026-02-12 v1 model: Add exploded view animation
    [mic固定座.SLDPRT, 底座（新）.SLDPRT, 电磁铁固定座.SLDPRT]
2026-04-01 prototype: Add sheet music for "Twinkle, Twinkle, Little Star" v1: 1. Add sheet music for "Twinkle, Twinkle, Little Star" 2. Update the screenplay
    [screenplay_zh.xlsx]
2026-04-02 v1 code: 1. Disable FPU in ISR and move gtimer/mcpwm functions into IRAM via menuconfig. Create a pure IRAM strum function to prevent cache misses and panics caused by calling Flash functions inside 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
    [play.c, servo_motor.c, uart_ctrl.c]
2026-04-15 v1: Update the screenplay. prototype: No model has been updated, Only generate an exploded view for animation.
    [screenplay_zh.xlsx, 尺子演奏器验证机.SLDASM, 底板.SLDPRT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]
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2026-04-30 Release Notes: 1. Added new project images. 2. Moved legacy models into a dedicated folder. 3. Fixed SolidWorks texture errors by including .p2d files. 4. Added the link to the PCB design files. 5. U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
    [10cm薄尺.SLDPRT, Guitar Pick 0.7mm.SLDPRT, INMP441 I2S Microphone Module v15.step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]
2026-05-08 DOCS: Revise README with accurate project structure and hardware details
    - Overhaul English README: correct directory layout, hardware specs, features
    based on actual firmware code
    - Add Chinese README (README_zh.md) with language switcher link
    - Replace hero image with real_Isometric.jpg; add exploded view, PCB photo,
    button info diagram, and Stationery Band roadmap image
    - Change license from MIT to CC BY-NC-SA 4.0; add LICENSE file
    - Add Bilibili demo video link and physics note on inharmonic overtones
    [terminal.c]
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2026-05-11 1.update the readme, add pcb config info 2.update the bom.
    [bom_zh.xlsx]

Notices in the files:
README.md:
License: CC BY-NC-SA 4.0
